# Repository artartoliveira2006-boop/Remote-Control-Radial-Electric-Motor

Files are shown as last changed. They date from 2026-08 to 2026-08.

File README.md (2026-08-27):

# Motor elétrico radial de cinco fases com controle remoto

Protótipo acadêmico de um motor elétrico radial construído com cinco bobinas e controle por uma placa baseada em ESP32. O projeto combina fabricação mecânica, acionamento eletromagnético, sequenciamento de fases e um comando remoto simples consultado pela internet.

<p align="center">
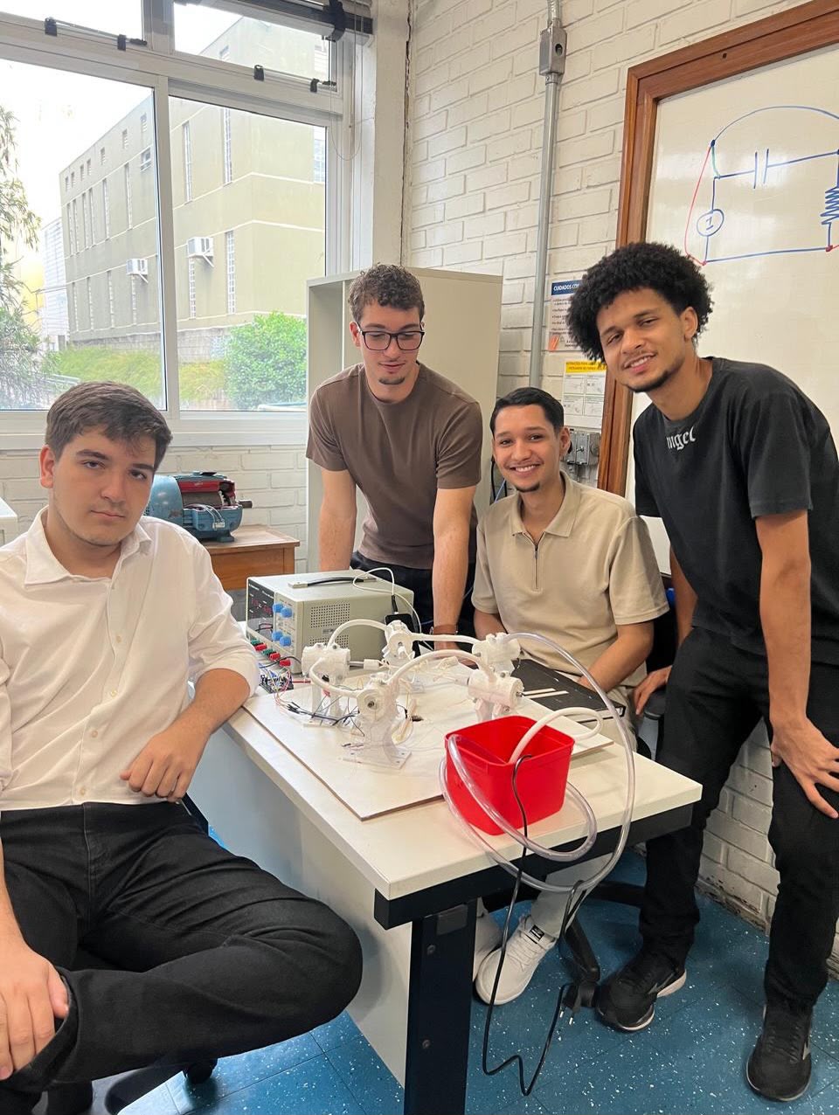
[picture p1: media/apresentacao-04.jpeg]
Equipe ao lado do protótipo de motor radial durante a apresentação
  
</p>

## Visão geral

O rotor é movimentado pela ativação sucessiva das cinco bobinas. O firmware oferece dois mapas de ligação (`MODO 1` e `MODO 2`) e percorre as posições pelo salto matemático `k = 2` em um conjunto de `n = 5`, formando a ordem radial em estrela. O intervalo entre ativações diminui exponencialmente, produzindo uma rampa de aceleração.

Uma tarefa separada do ESP32 consulta, a cada 10 segundos, o arquivo público [`commands.txt`](commands.txt). Os valores aceitos são:

- `MOTOR_ON`: inicia o sequenciamento e zera o cronômetro de aceleração;
- `MOTOR_OFF`: desliga todas as saídas das bobinas.

## Principais recursos

- controle de cinco bobinas por GPIO;
- teste automático individual das bobinas na inicialização;
- dois mapas de pinagem selecionáveis em compilação;
- sequência radial calculada por aritmética modular;
- aceleração com redução exponencial do intervalo entre passos;
- comando remoto por Wi-Fi e arquivo hospedado no GitHub;
- execução da comunicação em uma tarefa separada do sequenciamento.

## Estrutura do repositório

```text
.
|-- cad/
|   |-- bobina.stl
|   |-- encapsulamento-direito.stl
|   |-- encapsulamento-esquerdo.stl
|   `-- README.md
|-- docs/
|   |-- relatorio/
|   |   `-- Motor_Radial_Relatorio_Revisado.tex
|   `-- README.md
|-- firmware/
|   `-- MotorRadial/
|       |-- MotorRadial.ino
|       |-- arduino_secrets.example.h
|       |-- sequenciamento.ino
|       |-- sketch.json
|       |-- variaveis.h
|       `-- wifi.ino
|-- hardware/
|   `-- README.md
|-- media/
|   |-- inspiracao/
|   |   |-- campo-magnetico-solenoide.png
|   |   `-- motor-radial-fiat-a50.jpg
|   |-- apresentacao-01.jpeg
|   |-- apresentacao-02.jpeg
|   |-- apresentacao-03.jpeg
|   |-- apresentacao-04.jpeg
|   |-- demonstracao-01.mp4
|   |-- demonstracao-02.mp4
|   |-- demonstracao-03.mp4
|   |-- demonstracao-04.mp4
|   `-- README.md
|-- output/pdf/
|   `-- Motor_Radial_Relatorio_Revisado.pdf
|-- .gitignore
|-- commands.txt
`-- README.md
```

## Firmware

### Preparar as credenciais

Copie `firmware/MotorRadial/arduino_secrets.example.h` para `firmware/MotorRadial/arduino_secrets.h` e preencha a cópia local:

```cpp
#define SECRET_SSID "NOME_DA_REDE"
#define SECRET_PASSWORD "SENHA_DA_REDE"
```

O arquivo real de credenciais é ignorado pelo Git e não deve ser publicado.

O ZIP público do sketch original continha credenciais diretamente no código. Se aquela senha ainda estiver em uso, altere-a antes de voltar a conectar o protótipo.

### Compilar com Arduino CLI

```bash
arduino-cli core install esp32:esp32
arduino-cli compile --fqbn esp32:esp32:esp32 firmware/MotorRadial
```

A compilação usa `ESP32 Dev Module` como alvo de referência porque o sketch emprega números de GPIO brutos, Wi-Fi e recursos FreeRTOS específicos do ESP32. Confirme o modelo exato da placa física antes de gravar.

Validação realizada com Arduino CLI 1.5.1 e o núcleo oficial Espressif `esp32:esp32` 3.3.11:

- modo 1: 1.022.916 bytes de programa (78%) e 48.504 bytes de memória global (14%);
- modo 2: 1.022.920 bytes de programa (78%) e 48.504 bytes de memória global (14%).

## Sequenciamento

No modo padrão, o atraso entre passos começa em 800 ms e tende a 100 ms, com constante de decaimento de 40 s. O firmware imprime uma RPM estimada com base em uma relação assumida entre passos e revolução; esse valor ainda não foi validado com tacômetro.

Consulte [hardware/README.md](hardware/README.md) antes de energizar o protótipo.

## Atenção antes do primeiro teste

- as bobinas exigem estágio de potência e fonte externa adequada;
- a pinagem física ainda precisa ser confrontada com o protótipo e o Tinkercad;
- o teste de bobinas é executado automaticamente durante a inicialização;
- a função de conexão Wi-Fi aguarda indefinidamente até a rede ficar disponível;
- o comando remoto atual é público e não possui autenticação própria;
- a RPM mostrada no monitor serial é uma estimativa, não uma medição;
- tensão, corrente, aquecimento e velocidade máxima segura ainda precisam ser medidos.

Faça os primeiros testes com alimentação limitada, uma bobina por vez e possibilidade de desligamento imediato.

## Materiais do projeto

- [Sketch no Arduino Cloud](https://app.arduino.cc/sketches/5fc2e5a7-c3c3-415b-b562-e2339e4dc90b?view-mode=preview)
- [Circuito no Tinkercad](https://www.tinkercad.com/things/hriccYSg3r2-dazzling-gaaris-fulffy/editel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)
- [Relatório acadêmico revisado em PDF](output/pdf/Motor_Radial_Relatorio_Revisado.pdf)
- [Fonte LaTeX e instruções de compilação](docs/README.md)
- [Modelos STL para fabricação 3D](cad/README.md)
- [Fotos, vídeos e identificação do material](media/README.md)

## Autoria e contexto acadêmico

O protótipo foi desenvolvido por Arthur Artiaga Oliveira, Matheus Chacon de Moura, Miguel Resende de Faria Silva, Pedro Henrique Rodrigues Meireles e Rafael Valero Borges Alecrim, no curso de Engenharia Elétrica da PUC Minas, como atividade da disciplina Desafio de Engenharia Elétrica I, ministrada pela professora Viviane Reis de Carvalho, em 2026.

## English summary

This repository documents a custom five-phase radial electric motor controlled by an ESP32-class board. Five coils are driven in a star-like modular sequence, with an exponential acceleration ramp and a simple GitHub-hosted remote command. The repository includes sanitized firmware, printable STL meshes, photos, test videos and structured documentation for the circuit and academic report.

## Licença

Uma licença de reutilização ainda não foi definida. Até que os autores escolham uma licença, o conteúdo permanece protegido pelos direitos de seus respectivos autores.

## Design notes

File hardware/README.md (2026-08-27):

# Hardware e montagem

Este diretório registra o circuito de acionamento do motor radial de cinco bobinas. O [projeto compartilhado no Tinkercad](https://www.tinkercad.com/things/hriccYSg3r2-dazzling-gaaris-fulffy/editel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) pode exigir login na Autodesk.

## Sinais usados pelo firmware

No modo sequencial (`MODO == 1`), o firmware usa:

| Saída lógica | GPIO |
| --- | ---: |
| `COIL0_PIN` | 14 |
| `COIL1_PIN` | 17 |
| `COIL2_PIN` | 27 |
| `COIL3_PIN` | 25 |
| `COIL4_PIN` | 16 |

No modo radial (`MODO == 2`), os mesmos GPIOs são associados às saídas em outra ordem. A tabela descreve apenas o firmware; a correspondência física entre saída, transistor e bobina ainda deve ser conferida no protótipo.

## Acionamento e alimentação

As bobinas não podem ser ligadas diretamente aos GPIOs do microcontrolador. O sketch menciona um ULN2003 como estágio de potência. Antes de energizar:

1. confirme a tensão e a corrente nominal de cada bobina;
2. use fonte externa dimensionada para a corrente simultânea prevista;
3. mantenha o GND da fonte, do driver e da placa em comum;
4. confirme a ligação das proteções contra tensão reversa do driver;
5. teste uma bobina por vez, por intervalo curto, observando aquecimento;
6. mantenha um meio físico de cortar a alimentação das bobinas.

O programa executa um teste automático de todas as bobinas na inicialização. Não energize a potência antes de confirmar a pinagem e os limites térmicos.

## Dados ainda necessários

- modelo exato da placa ESP32;
- modelo e quantidade dos drivers;
- tensão, resistência e corrente das bobinas;
- tensão e corrente máxima da fonte;
- diagrama definitivo das ligações;
- identificação física das bobinas 0 a 4.

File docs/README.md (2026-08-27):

# Documentação

O relatório acadêmico foi revisado com base no documento original da equipe e na organização adotada no relatório do projeto da garra articulada.

Arquivos disponíveis:

- [`relatorio/Motor_Radial_Relatorio_Revisado.tex`](relatorio/Motor_Radial_Relatorio_Revisado.tex): fonte editável em LaTeX;
- [`../output/pdf/Motor_Radial_Relatorio_Revisado.pdf`](../output/pdf/Motor_Radial_Relatorio_Revisado.pdf): versão compilada e revisada.

A revisão acrescenta elementos pré-textuais, imagens do projeto, referências visuais licenciadas, tabelas de pinagem e fabricação, metodologia, verificações, segurança e propostas de evolução. Afirmações sobre eficiência, torque, RPM e desempenho térmico foram limitadas ao que pode ser sustentado pelas evidências disponíveis.

Para recompilar a partir da raiz do repositório:

```bash
pdflatex -interaction=nonstopmode -halt-on-error -output-directory=output/pdf docs/relatorio/Motor_Radial_Relatorio_Revisado.tex
pdflatex -interaction=nonstopmode -halt-on-error -output-directory=output/pdf docs/relatorio/Motor_Radial_Relatorio_Revisado.tex
```

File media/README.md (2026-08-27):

# Fotos e vídeos

Este diretório preserva quatro registros fotográficos do dia da apresentação e quatro vídeos recebidos junto aos materiais do projeto.

## Fotos

- `apresentacao-01.jpeg`: demonstração do protótipo em bancada;
- `apresentacao-02.jpeg`: equipe e docente junto ao protótipo;
- `apresentacao-03.jpeg`: explicação durante a apresentação;
- `apresentacao-04.jpeg`: equipe junto ao protótipo.

## Vídeos

| Arquivo | Duração | Orientação |
| --- | ---: | --- |
| `demonstracao-01.mp4` | 39 s | horizontal |
| `demonstracao-02.mp4` | 8 s | vertical |
| `demonstracao-03.mp4` | 17 s | horizontal |
| `demonstracao-04.mp4` | 4 min | horizontal |

Os vídeos foram mantidos com nomes neutros porque o conteúdo individual ainda não foi reproduzido nesta revisão. Após confirmação, eles podem receber nomes específicos como `motor-em-funcionamento.mp4` e `teste-bobina-01.mp4`.

As imagens mostram integrantes, docentes e/ou visitantes. A equipe deve manter no repositório apenas os registros cuja publicação tenha sido autorizada.

## Imagens de inspiração

- `inspiracao/motor-radial-fiat-a50.jpg`: motor radial aeronáutico Fiat A.50 seccionado, fotografia de MLWatts, Wikimedia Commons, licença CC BY-SA 3.0;
- `inspiracao/campo-magnetico-solenoide.png`: representação das linhas de campo de um solenoide, por Nuno Nogueira, Wikimedia Commons, domínio público.

Essas imagens são usadas no relatório como referências visuais e conceituais. Elas não representam componentes idênticos aos empregados no protótipo.

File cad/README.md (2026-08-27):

# Modelos para fabricação 3D

Esta pasta contém três malhas STL binárias fornecidas a partir do projeto mecânico:

| Arquivo | Função informada | Triângulos | Dimensões da malha (X x Y x Z) |
| --- | --- | ---: | --- |
| `bobina.stl` | Corpo/suporte da bobina | 1.804 | 40,00 x 39,98 x 80,00 |
| `encapsulamento-esquerdo.stl` | Metade esquerda do encapsulamento | 766 | 29,00 x 64,27 x 80,00 |
| `encapsulamento-direito.stl` | Metade direita do encapsulamento | 766 | 24,00 x 64,27 x 80,00 |

As dimensões acima foram calculadas a partir dos limites geométricos dos arquivos. O formato STL não armazena a unidade de medida; confirme no software de modelagem ou fatiamento se os valores devem ser interpretados em milímetros antes de fabricar.

## Arquivos que ainda podem complementar o projeto

- modelo paramétrico original ou conjunto em `.step`/`.stp`;
- imagem renderizada ou captura da montagem completa;
- nome e versão do software usado na modelagem;
- orientação, preenchimento, material e demais parâmetros de impressão;
- tolerâncias e método de união das duas metades do encapsulamento.

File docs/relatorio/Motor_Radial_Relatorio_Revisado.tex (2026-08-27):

\documentclass[12pt,a4paper,oneside]{article}

\usepackage[T1]{fontenc}
\usepackage[utf8]{inputenc}
\usepackage{lmodern}
\usepackage[english,brazilian]{babel}
\usepackage{geometry}
\usepackage{graphicx}
\usepackage{booktabs}
\usepackage{tabularx}
\usepackage{array}
\usepackage{longtable}
\usepackage{enumitem}
\usepackage{caption}
\usepackage{float}
\usepackage{xcolor}
\usepackage{fancyhdr}
\usepackage{titlesec}
\usepackage{microtype}
\usepackage{setspace}
\usepackage{hyperref}
\usepackage{url}

\geometry{top=2.5cm,bottom=2.2cm,left=3cm,right=2cm,headheight=24pt}
\setlength{\parindent}{1.25cm}
\setlength{\parskip}{0pt}
\onehalfspacing
\emergencystretch=2em

\definecolor{navy}{HTML}{15324A}
\definecolor{blue}{HTML}{247BA0}
\definecolor{cyan}{HTML}{5BC0BE}
\definecolor{pale}{HTML}{EAF4F7}
\definecolor{orange}{HTML}{F28F3B}
\definecolor{dark}{HTML}{202A33}

\hypersetup{
  colorlinks=true,
  linkcolor=navy,
  urlcolor=blue,
  citecolor=navy,
  pdftitle={Motor radial elétrico experimental de cinco atuadores},
  pdfauthor={Arthur Artiaga Oliveira; Matheus Chacon de Moura; Miguel Resende de Faria Silva; Pedro Henrique Rodrigues Meireles; Rafael Valero Borges Alecrim}
}

\titleformat{\section}{\normalfont\Large\bfseries\color{navy}}{\thesection}{0.6em}{}
\titleformat{\subsection}{\normalfont\large\bfseries\color{blue}}{\thesubsection}{0.6em}{}
\titleformat{\subsubsection}{\normalfont\normalsize\bfseries\color{dark}}{\thesubsubsection}{0.6em}{}
\titlespacing*{\section}{0pt}{1.5em}{0.7em}
\titlespacing*{\subsection}{0pt}{1.1em}{0.5em}

\pagestyle{fancy}
\fancyhf{}
\fancyhead[L]{\footnotesize\color{navy} MOTOR RADIAL ELÉTRICO EXPERIMENTAL}
\fancyhead[R]{\footnotesize\color{gray} PUC MINAS}
\fancyfoot[C]{\thepage}
\renewcommand{\headrulewidth}{0.4pt}
\renewcommand{\headrule}{\hbox to\headwidth{\color{cyan}\leaders\hrule height \headrulewidth\hfill}}

\captionsetup{font=small,labelfont=bf,textfont=it,justification=centering}
\setlist[itemize]{leftmargin=1.2cm,itemsep=0.2em,topsep=0.4em}
\newcolumntype{Y}{>{\raggedright\arraybackslash}X}
\renewcommand{\refname}{REFERÊNCIAS}
\newcommand{\source}[1]{\par\centering\footnotesize\itshape Fonte: #1\par}
\newcommand{\warningbox}[1]{%
  \begin{center}
  \colorbox{pale}{\parbox{0.92\textwidth}{\color{navy}\small #1}}
  \end{center}
}

\begin{document}
\hypersetup{pageanchor=false}

% Capa
\begin{titlepage}
  \pagecolor{navy}\color{white}
  \noindent {\large INSTITUTO POLITÉCNICO - PUC MINAS}\\[0.25cm]
  {\large CURSO DE ENGENHARIA ELÉTRICA}

  \vspace{3.2cm}
  {\fontsize{25}{31}\selectfont\bfseries
  DESENVOLVIMENTO DE UM MOTOR RADIAL ELÉTRICO EXPERIMENTAL DE CINCO ATUADORES\par}

  \vspace{0.8cm}
  {\color{orange}\rule{0.48\textwidth}{2.2pt}}\\[0.8cm]
  {\large Controle embarcado, fabricação aditiva e investigação de resfriamento líquido}

  \vfill
  {\normalsize
  Arthur Artiaga Oliveira\\
  Matheus Chacon de Moura\\
  Miguel Resende de Faria Silva\\
  Pedro Henrique Rodrigues Meireles\\
  Rafael Valero Borges Alecrim}

  \vspace{1.2cm}
  {\normalsize Belo Horizonte - MG\\2026}
\end{titlepage}
\nopagecolor\color{dark}

% Folha de rosto, seguindo a estrutura do relatório de referência
\begin{titlepage}
  \begin{center}
    {\normalsize
    Arthur Artiaga Oliveira\\
    Matheus Chacon de Moura\\
    Miguel Resende de Faria Silva\\
    Pedro Henrique Rodrigues Meireles\\
    Rafael Valero Borges Alecrim}

    \vspace{3.2cm}
    {\Large\bfseries DESENVOLVIMENTO DE UM MOTOR RADIAL ELÉTRICO EXPERIMENTAL DE CINCO ATUADORES\par}
  \end{center}

  \vspace{3.2cm}
  \hfill\begin{minipage}{0.52\textwidth}
    Trabalho apresentado ao Curso de Engenharia Elétrica da Pontifícia Universidade Católica de Minas Gerais, no âmbito da disciplina Desafio de Engenharia Elétrica I.

    \vspace{0.5cm}
    Professora: Viviane Reis de Carvalho.
  \end{minipage}

  \vfill
  \begin{center}
    Belo Horizonte - MG\\
    2026
  \end{center}
\end{titlepage}

\hypersetup{pageanchor=true}
\pagenumbering{roman}

\section*{RESUMO}
\addcontentsline{toc}{section}{Resumo}
Este relatório descreve o desenvolvimento de um protótipo didático de motor radial elétrico com cinco atuadores eletromagnéticos dispostos em estrela. A estrutura combina peças impressas em 3D, base de madeira e componentes metálicos reaproveitados. Um microcontrolador ESP32 executa o acionamento sequencial das bobinas por intermédio de um estágio ULN2003 e consulta, via Wi-Fi, um comando textual hospedado no GitHub. O firmware implementa duas ordens de comutação, teste individual dos atuadores e redução progressiva do intervalo entre passos. As demonstrações registradas confirmam qualitativamente a energização das bobinas e o movimento do conjunto; entretanto, não foram disponibilizadas medições instrumentais de rotação, torque, corrente ou temperatura. Por esse motivo, o desempenho e a efetividade do resfriamento líquido são tratados como aspectos ainda sujeitos a validação experimental. O trabalho evidencia a integração entre eletromagnetismo, sistemas embarcados, fabricação aditiva e reaproveitamento de materiais, além de estabelecer uma base documentada para ensaios futuros.

\noindent\textbf{Palavras-chave:} motor radial; eletromagnetismo; ESP32; ULN2003; fabricação aditiva; protótipo didático.
\clearpage

\selectlanguage{english}
\section*{ABSTRACT}
\addcontentsline{toc}{section}{Abstract}
This report describes the development of a didactic radial electric motor prototype with five electromagnetic actuators arranged in a star pattern. Its structure combines 3D-printed parts, a wooden base and reused metallic components. An ESP32 microcontroller sequentially drives the coils through a ULN2003 stage and checks a text command hosted on GitHub over Wi-Fi. The firmware provides two switching orders, individual actuator testing and a progressive reduction of the interval between steps. Available demonstrations qualitatively confirm coil energization and motion of the assembly; however, no instrumented measurements of speed, torque, current or temperature were available. Performance and liquid-cooling effectiveness are therefore identified as subjects for future experimental validation. The project integrates electromagnetism, embedded systems, additive manufacturing and material reuse while establishing a documented baseline for further testing.

\noindent\textbf{Keywords:} radial motor; electromagnetism; ESP32; ULN2003; additive manufacturing; educational prototype.
\selectlanguage{brazilian}
\clearpage

\listoffigures
\addcontentsline{toc}{section}{Lista de figuras}
\clearpage

\section*{LISTA DE SIGLAS E ABREVIATURAS}
\addcontentsline{toc}{section}{Lista de siglas e abreviaturas}
\begin{tabularx}{\textwidth}{>{\bfseries}l Y}
CAD & Computer-Aided Design (projeto auxiliado por computador)\\
ESP32 & Família de microcontroladores com conectividade sem fio da Espressif\\
FreeRTOS & Sistema operacional de tempo real usado pelo firmware\\
GPIO & General-Purpose Input/Output (entrada e saída de uso geral)\\
HTTP & Hypertext Transfer Protocol\\
IoT & Internet of Things (Internet das Coisas)\\
RPM & Rotações por minuto\\
STL & Formato de malha empregado na fabricação aditiva\\
Wi-Fi & Tecnologia de comunicação em rede sem fio\\
\end{tabularx}
\clearpage

\tableofcontents
\clearpage
\pagenumbering{arabic}

\section{INTRODUÇÃO}

Motores elétricos convertem energia elétrica em energia mecânica por meio da interação entre campos magnéticos. No protótipo estudado, essa conversão é explorada em uma arquitetura inspirada visualmente nos motores radiais: cinco eletroímãs são distribuídos ao redor de um conjunto móvel central e acionados em sequência.

A proposta foi desenvolvida no primeiro semestre do curso de Engenharia Elétrica como exercício interdisciplinar. Além da montagem eletromecânica, o trabalho reuniu modelagem CAD, impressão 3D, programação embarcada, comunicação em rede e reaproveitamento de materiais. O resultado deve ser compreendido como protótipo experimental e didático, não como máquina elétrica caracterizada para operação contínua.

\warningbox{Esta versão revisada separa fatos documentados de hipóteses e observações. Afirmações quantitativas sobre eficiência, torque, velocidade ou desempenho térmico somente poderão ser feitas após ensaios instrumentados.}

\subsection{Problemática e justificativa}

O desafio consistiu em produzir movimento rotativo a partir do acionamento coordenado de cinco bobinas, usando uma estrutura de baixo custo e um controlador programável. O aquecimento por efeito Joule motivou também a incorporação de passagens para circulação de água nos encapsulamentos das bobinas, conceito que requer validação térmica posterior.

A documentação técnica é parte do problema de engenharia. Sem o registro de pinagem, lógica de controle, modelos de fabricação e limitações dos ensaios, torna-se difícil reproduzir o protótipo ou comparar futuras alterações. Assim, este relatório reúne o estado conhecido do sistema e explicita os dados que ainda precisam ser medidos.

\subsection{Referências visuais e conceituais}

A organização em estrela foi inspirada na leitura visual dos motores radiais aeronáuticos, nos quais os cilindros se distribuem ao redor de um eixo central. A semelhança é geométrica: o protótipo elétrico não reproduz combustão interna, bielas articuladas ou o ciclo termodinâmico dessas máquinas.

\begin{figure}[H]
  \centering
  
  \caption{Motor aeronáutico radial Fiat A.50 seccionado, referência para a disposição em estrela.}
  \source{MLWatts, Wikimedia Commons, 2012, licença CC BY-SA 3.0.}
\end{figure}

O princípio de atuação, por sua vez, vem do campo magnético produzido por uma bobina energizada. A Figura~\ref{fig:solenoide} é conceitual e não representa a geometria exata dos atuadores construídos.

\begin{figure}[H]
  \centering
  
  \caption{Representação aproximada das linhas de campo de um solenoide.}
  \label{fig:solenoide}
  \source{Nuno Nogueira, Wikimedia Commons, domínio público.}
\end{figure}

\subsection{Objetivos}

\subsubsection{Objetivo geral}

Projetar, construir e demonstrar um protótipo de motor radial elétrico com cinco atuadores, controle embarcado e componentes produzidos por fabricação aditiva.

\subsubsection{Objetivos específicos}

\begin{itemize}
  \item modelar e fabricar suportes e encapsulamentos por impressão 3D;
  \item construir e testar cinco bobinas eletromagnéticas;
  \item implementar o acionamento sequencial por ESP32 e ULN2003;
  \item permitir habilitação remota por consulta a um comando hospedado no GitHub;
  \item investigar uma solução de circulação de água para remoção de calor;
  \item documentar limitações e definir ensaios para a continuidade do projeto.
\end{itemize}

\section{REFERENCIAL TEÓRICO}

\subsection{Eletromagnetismo e atuação}

A corrente elétrica que percorre uma bobina produz um campo magnético. Quando o atuador é energizado, esse campo exerce força sobre o elemento ferromagnético associado ao mecanismo móvel. A repetição ordenada das atrações produz deslocamentos angulares sucessivos. A intensidade da força depende, entre outros fatores, da corrente, do número de espiras, da geometria do núcleo e do entreferro \cite{halliday,fitzgerald}.

\subsection{Aquecimento por efeito Joule}

A dissipação elétrica em uma bobina pode ser estimada por
\begin{equation}
  P = R I^2,
\end{equation}
em que $P$ é a potência dissipada, $R$ é a resistência do enrolamento e $I$ é a corrente. Como o aquecimento varia com o quadrado da corrente, a caracterização elétrica e térmica é essencial antes de aumentar o tempo de energização ou a tensão de alimentação.

\subsection{Controle embarcado e estágio de potência}

Os pinos do ESP32 fornecem sinais lógicos e não devem alimentar bobinas diretamente. O ULN2003 reúne transistores Darlington usados como chaves de baixa tensão, permitindo que os sinais do microcontrolador comandem cargas ligadas a uma fonte externa \cite{tiuln}. O retorno de corrente, a conexão comum dos diodos internos, o aterramento compartilhado e os limites elétricos do componente precisam ser respeitados na montagem.

\begin{figure}[H]
  \centering
  \setlength{\fboxsep}{8pt}
  \fbox{Comando remoto GitHub}
  $\longrightarrow$
  \fbox{ESP32 + Wi-Fi}
  $\longrightarrow$
  \fbox{ULN2003}
  $\longrightarrow$
  \fbox{5 bobinas}
  \caption{Arquitetura funcional documentada do protótipo.}
  \source{Elaboração própria.}
\end{figure}

\subsection{Configuração radial}

Nos motores aeronáuticos radiais, cilindros são distribuídos ao redor de um eixo comum. Neste trabalho, a configuração foi reinterpretada como disposição de cinco atuadores eletromagnéticos em estrela. A comparação orienta a forma do conjunto, mas não implica equivalência entre os princípios de conversão de energia.

\section{METODOLOGIA E DESENVOLVIMENTO}

\subsection{Fluxo de atividades}

O desenvolvimento foi conduzido em etapas interdependentes:
\begin{enumerate}[leftmargin=1.4cm]
  \item definição da configuração radial e modelagem das peças;
  \item impressão dos suportes e encapsulamentos;
  \item construção dos enrolamentos e montagem dos elementos ferromagnéticos;
  \item integração mecânica sobre a base de madeira;
  \item montagem do ESP32 e do estágio ULN2003;
  \item desenvolvimento e compilação do firmware;
  \item teste individual das cinco saídas;
  \item execução da sequência e registro da demonstração.
\end{enumerate}

\subsection{Componentes utilizados}

\begin{table}[H]
\centering
\caption{Componentes identificados na documentação disponível.}
\begin{tabularx}{\textwidth}{>{\bfseries}p{4.2cm}Y}
\toprule
Componente & Função no protótipo\\
\midrule
ESP32 & Sequenciamento das bobinas e consulta ao comando remoto por Wi-Fi.\\
ULN2003 & Chaveamento das cargas a partir dos sinais lógicos do ESP32.\\
Cinco bobinas & Produção dos campos magnéticos de atuação.\\
Fonte externa & Alimentação do estágio de potência e dos enrolamentos.\\
Peças impressas em 3D & Suporte das bobinas e encapsulamento com passagens para água.\\
Base de madeira & Sustentação do conjunto eletromecânico.\\
Componentes metálicos & Elementos móveis, eixo e partes ferromagnéticas.\\
Tubulações e reservatório & Circulação experimental de água nos encapsulamentos.\\
\bottomrule
\end{tabularx}
\end{table}

\subsection{Estrutura mecânica e fabricação aditiva}

A montagem adota cinco posições radiais em torno do rotor. A base foi construída em madeira e recebeu componentes metálicos reutilizados. Foram disponibilizadas três malhas STL: suporte da bobina e metades esquerda e direita do encapsulamento. Como o formato STL não registra unidade, as dimensões devem ser confirmadas no software CAD ou fatiador antes da fabricação.

\begin{table}[H]
\centering
\caption{Características extraídas das malhas STL.}
\begin{tabularx}{\textwidth}{Y c c}
\toprule
Modelo & Triângulos & Dimensões geométricas X $\times$ Y $\times$ Z\\
\midrule
Bobina & 1.804 & 40,00 $\times$ 39,98 $\times$ 80,00\\
Encapsulamento esquerdo & 766 & 29,00 $\times$ 64,27 $\times$ 80,00\\
Encapsulamento direito & 766 & 24,00 $\times$ 64,27 $\times$ 80,00\\
\bottomrule
\end{tabularx}
\end{table}

As dimensões da Tabela 2 são limites geométricos da malha. As unidades não são codificadas no arquivo e precisam ser confirmadas antes da impressão.

\subsection{Subsistema eletromagnético e resfriamento}

Cada atuador é formado por um enrolamento de fio de cobre esmaltado e um elemento ferromagnético móvel. Os encapsulamentos foram concebidos com passagens para água. A existência desse circuito de circulação é documentada, mas sua contribuição térmica ainda não foi quantificada por comparação de temperaturas, vazões ou tempos de operação.

\begin{figure}[H]
  \centering
  \begin{tabular}{cc}
     &
     \\
     &
    
  \end{tabular}
  \caption{Registros do protótipo e da apresentação acadêmica.}
  \source{Acervo da equipe.}
\end{figure}

\subsection{Eletrônica e pinagem}

\begin{table}[H]
\centering
\caption{Mapeamentos definidos no firmware.}
\small
\begin{tabularx}{\textwidth}{p{2.5cm} >{\centering\arraybackslash}p{2.7cm} >{\centering\arraybackslash}p{2.7cm} Y}
\toprule
Canal lógico & GPIO no modo 1 & GPIO no modo 2 & Função\\
\midrule
Bobina 0 & 14 & 17 & Primeiro atuador da sequência\\
Bobina 1 & 17 & 25 & Segundo atuador da sequência\\
Bobina 2 & 27 & 14 & Terceiro atuador da sequência\\
Bobina 3 & 25 & 16 & Quarto atuador da sequência\\
Bobina 4 & 16 & 27 & Quinto atuador da sequência\\
\bottomrule
\end{tabularx}
\end{table}

\warningbox{O circuito completo do Tinkercad depende de autenticação para inspeção. A documentação disponível ainda não confirma tensão da fonte, resistência das bobinas, corrente por canal, ligação do terminal COM ou capacidade térmica do driver.}

\subsection{Programação do sistema de controle}

\subsubsection{Organização geral}

O firmware foi organizado em módulos para variáveis, sequenciamento e comunicação Wi-Fi. As credenciais de rede foram removidas do código versionado e substituídas por um arquivo local ignorado pelo Git. Uma tarefa FreeRTOS fixada ao segundo núcleo consulta periodicamente o comando remoto, enquanto o laço principal executa a sequência eletromagnética.

\subsubsection{Teste de inicialização}

Antes da rotina principal, as cinco saídas são acionadas individualmente. Essa etapa permite verificar a resposta de cada canal, mas deve ser executada com alimentação limitada e possibilidade de desligamento imediato.

\subsubsection{Sequência e aceleração}

A posição lógica seguinte é obtida por aritmética modular, fazendo a sequência retornar ao início após a quinta bobina. O intervalo entre passos parte de aproximadamente 800 ms e decresce exponencialmente em direção a 100 ms, com constante temporal configurada em 40 s. O número apresentado como RPM no monitor serial é uma estimativa baseada em uma relação assumida entre passos e revolução; não substitui medição por tacômetro.

\begin{table}[H]
\centering
\caption{Modos de sequência do firmware revisado.}
\begin{tabularx}{0.78\textwidth}{c Y c}
\toprule
Modo & Ordem dos GPIOs & Compilação\\
\midrule
1 & 14, 17, 27, 25, 16 & Aprovada\\
2 & 17, 25, 14, 16, 27 & Aprovada\\
\bottomrule
\end{tabularx}
\end{table}

\subsubsection{Comando remoto}

O ESP32 realiza uma requisição HTTP ao arquivo \texttt{commands.txt} hospedado no GitHub. Quando recebe o texto \texttt{MOTOR\_ON}, habilita o funcionamento; qualquer outro conteúdo desabilita o acionamento. Essa solução é adequada à demonstração, mas não oferece autenticação própria, resposta em tempo real garantida ou proteção contra indisponibilidade da rede.

\section{TESTES E VERIFICAÇÕES}

\subsection{Verificação de software}

A versão sanitizada foi compilada com Arduino CLI 1.5.1 para o alvo ESP32 Dev Module, usando o núcleo oficial Espressif \texttt{esp32:esp32} 3.3.11. Os dois modos de pinagem compilaram sem erro.

\begin{table}[H]
\centering
\caption{Resultado da compilação do firmware.}
\begin{tabularx}{0.88\textwidth}{p{3cm} Y Y}
\toprule
Configuração & Programa & Memória global\\
\midrule
Modo 1 & 1.022.916 bytes (78\%) & 48.504 bytes (14\%)\\
Modo 2 & 1.022.920 bytes (78\%) & 48.504 bytes (14\%)\\
\bottomrule
\end{tabularx}
\end{table}

Esse ensaio verifica a consistência do software e das dependências de compilação. Ele não comprova o comportamento elétrico do protótipo.

\subsection{Testes documentados}

Os materiais fornecidos incluem registros da apresentação, vídeos do motor e testes das bobinas. Esses registros permitem documentar a construção e a ocorrência de resposta eletromecânica. Não foram disponibilizados arquivos de aquisição de dados ou instrumentos de medição associados aos testes.

\subsection{Procedimento recomendado para ensaios futuros}

\begin{enumerate}[leftmargin=1.4cm]
  \item medir resistência e continuidade de cada bobina com o sistema desligado;
  \item energizar um canal por vez com fonte limitada em corrente;
  \item registrar tensão, corrente e temperatura em intervalos definidos;
  \item verificar a ordem física das bobinas em baixa velocidade;
  \item medir RPM com sensor óptico ou Hall;
  \item repetir o ensaio térmico com circulação desligada e ligada;
  \item registrar vazão, temperatura ambiente e tempo de operação;
  \item interromper imediatamente o teste diante de aquecimento, vazamento ou travamento.
\end{enumerate}

\section{RESULTADOS E DISCUSSÃO}

\subsection{Evidências disponíveis}

As fotografias e os vídeos disponibilizados registram o protótipo, a apresentação e demonstrações associadas ao motor e às bobinas. O material sustenta a conclusão qualitativa de que o conjunto foi construído e apresentado e de que houve resposta eletromecânica durante os testes. O firmware disponível também documenta o acionamento das cinco saídas e a lógica de habilitação remota.

\subsection{Limites das conclusões}

\begin{longtable}{p{2.6cm}p{5.0cm}p{7.0cm}}
\caption{Separação entre evidência disponível e caracterização pendente.}\\
\toprule
\textbf{Aspecto} & \textbf{O que está documentado} & \textbf{O que ainda deve ser medido}\\
\midrule
\endfirsthead
\toprule
\textbf{Aspecto} & \textbf{O que está documentado} & \textbf{O que ainda deve ser medido}\\
\midrule
\endhead
Movimento & Observação audiovisual & RPM real, estabilidade e faixa operacional\\
Atuação & Teste sequencial de cinco saídas & Corrente, força e repetibilidade por bobina\\
Térmica & Encapsulamento com circulação de água & Temperatura, vazão e comparação com e sem fluxo\\
Desempenho & Protótipo funcional em demonstração & Torque, potência mecânica, rendimento e autonomia\\
Controle remoto & Consulta HTTP ao GitHub & Latência, falhas de rede e segurança\\
\bottomrule
\end{longtable}

\warningbox{Sem dados instrumentais, não é possível afirmar ganho de eficiência, redução mensurável de temperatura ou controle preciso de velocidade. Essas afirmações foram retiradas da conclusão para preservar a validade acadêmica do relatório.}

\subsection{Relevância acadêmica}

O protótipo integra conceitos de eletromagnetismo, eletrônica de potência, sistemas embarcados, programação concorrente, fabricação aditiva e segurança experimental. As limitações encontradas não anulam seu valor didático; ao contrário, definem problemas concretos de dimensionamento e instrumentação para uma próxima etapa.

\section{SUSTENTABILIDADE E SEGURANÇA}

\subsection{Reaproveitamento de materiais}

A base de madeira e os componentes metálicos reaproveitados reduziram a necessidade de aquisição de material novo. A fabricação aditiva também permitiu produzir geometrias específicas para o protótipo. Uma avaliação ambiental completa, contudo, exigiria contabilizar massa de material, consumo de impressão, descarte e possibilidade de reutilização.

\subsection{Cuidados para novos ensaios}

\begin{itemize}
  \item usar fonte com limitação de corrente e proteção adequada;
  \item confirmar a corrente máxima das bobinas e a dissipação admissível do ULN2003;
  \item garantir aterramento comum e diodos de roda livre corretamente conectados;
  \item manter água e conexões hidráulicas isoladas da eletrônica;
  \item monitorar a temperatura dos enrolamentos e do driver;
  \item prever desligamento imediato e impedir contato com partes móveis;
  \item não operar o motor sem supervisão enquanto os limites não forem caracterizados.
\end{itemize}

\section{PROPOSTAS DE OTIMIZAÇÃO E EVOLUÇÃO}

\begin{itemize}
  \item medir resistência e indutância de cada bobina;
  \item registrar tensão e corrente por canal com e sem carga;
  \item medir RPM por sensor óptico ou Hall e torque por bancada apropriada;
  \item comparar curvas de temperatura com circulação desligada e ligada;
  \item documentar vazão, fluido, vedação e pressão do circuito de resfriamento;
  \item substituir a consulta pública por uma interface autenticada e tolerante a falhas;
  \item validar esquemático, dimensionamento do driver e modelo exato da placa ESP32;
  \item preservar o arquivo CAD paramétrico e registrar parâmetros de impressão.
\end{itemize}

\section{CONCLUSÃO}

O projeto atingiu seu propósito didático ao integrar uma montagem mecânica radial, cinco atuadores eletromagnéticos, fabricação aditiva, controle por ESP32 e comunicação em rede. O protótipo e seus registros demonstram a realização prática da proposta e oferecem uma plataforma concreta para estudo de comutação, eletromagnetismo e sistemas embarcados.

A principal contribuição desta revisão é tornar explícita a diferença entre funcionamento observado e desempenho medido. A compilação do firmware foi verificada, mas as grandezas elétricas, mecânicas e térmicas permanecem sem caracterização quantitativa. A continuidade do trabalho deve priorizar esses ensaios e a segurança do estágio de potência.

Com a documentação do código, das malhas STL e das limitações atuais, o projeto passa a contar com uma base mais reproduzível e tecnicamente defensável para aperfeiçoamentos futuros.

\clearpage
\phantomsection\addcontentsline{toc}{section}{Referências}
\begin{thebibliography}{99}
\bibitem{chapman} CHAPMAN, Stephen J. \textit{Fundamentos de máquinas elétricas}. 5. ed. Porto Alegre: AMGH, 2013.

\bibitem{espressif} ESPRESSIF SYSTEMS. \textit{ESP32 Series Datasheet}. Documentação técnica do fabricante. Disponível em: \url{https://www.espressif.com/en/support/documents/technical-documents}. Acesso em: 27 ago. 2026.

\bibitem{fitzgerald} FITZGERALD, A. E.; KINGSLEY JR., C.; UMANS, S. D. \textit{Máquinas elétricas}. 7. ed. Porto Alegre: Bookman, 2014.

\bibitem{halliday} HALLIDAY, D.; RESNICK, R.; WALKER, J. \textit{Fundamentos de física}. v. 3. Rio de Janeiro: LTC, 2016.

\bibitem{fiat} MLWATTS. \textit{Fiat A.50 radial engine front view}. Wikimedia Commons, 2012. Licença CC BY-SA 3.0. Disponível em: \url{https://commons.wikimedia.org/wiki/File:Fiat_A.50_radial_engine_front_view.JPG}. Acesso em: 27 ago. 2026.

\bibitem{solenoide} NOGUEIRA, Nuno. \textit{Solenoid Rotated}. Wikimedia Commons, 2009. Domínio público. Disponível em: \url{https://commons.wikimedia.org/wiki/File:Solenoid_Rotated.svg}. Acesso em: 27 ago. 2026.

\bibitem{sedra} SEDRA, A. S.; SMITH, K. C. \textit{Microeletrônica}. 7. ed. São Paulo: Pearson, 2015.

\bibitem{tiuln} TEXAS INSTRUMENTS. \textit{ULN200x, ULQ200x High-Voltage, High-Current Darlington Transistor Arrays}. Datasheet. Disponível em: \url{https://www.ti.com/lit/ds/symlink/uln2003a.pdf}. Acesso em: 27 ago. 2026.
\end{thebibliography}

\clearpage
\section*{APÊNDICE A - REPOSITÓRIO E MATERIAIS}
\addcontentsline{toc}{section}{Apêndice A - Repositório e materiais}

\noindent\textbf{Repositório do projeto:}\\
\href{https://github.com/artartoliveira2006-boop/Remote-Control-Radial-Electric-Motor}{GitHub - Remote-Control-Radial-Electric-Motor}

\noindent\textbf{Sketch de origem:}\\
\href{https://app.arduino.cc/sketches/5fc2e5a7-c3c3-415b-b562-e2339e4dc90b?view-mode=preview}{Arduino Cloud - MotorRadial}

\noindent\textbf{Circuito compartilhado:}\\
\href{https://www.tinkercad.com/things/hriccYSg3r2-dazzling-gaaris-fulffy}{Tinkercad - circuito compartilhado}

O repositório preserva o firmware sanitizado, arquivos STL, fotografias, vídeos e documentação complementar. Credenciais de rede não fazem parte dos arquivos versionados.

\end{document}

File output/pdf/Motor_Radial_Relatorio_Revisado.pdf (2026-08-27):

### INSTITUTO POLITÉCNICO - PUC MINAS

### CURSO DE ENGENHARIA ELÉTRICA

# DESENVOLVIMENTO DE UM MOTOR RADIAL ELÉTRICO EX-

# PERIMENTAL DE CINCO ATUA-

# DORES

### Controle embarcado, fabricação aditiva e investigação de resfriamento líquido

Arthur Artiaga Oliveira
Matheus Chacon de Moura
Miguel Resende de Faria Silva Pedro Henrique Rodrigues Meireles Rafael Valero Borges Alecrim

Belo Horizonte - MG

Arthur Artiaga Oliveira
Matheus Chacon de Moura
Miguel Resende de Faria Silva Pedro Henrique Rodrigues Meireles Rafael Valero Borges Alecrim

## DESENVOLVIMENTO DE UM MOTOR RADIAL ELÉTRICO EXPERIMENTAL DE CINCO

## ATUADORES

Trabalho apresentado ao Curso de Engenharia Elétrica da Pontifícia Universidade Católica de Minas Gerais, no âmbito da disciplina Desafio de Engenharia Elétrica I.

Professora: Viviane Reis de Carvalho.

Belo Horizonte - MG
2026

MOTOR RADIAL ELÉTRICO EXPERIMENTAL | PUC MINAS

## RESUMO

Este relatório descreve o desenvolvimento de um protótipo didático de motor radial elétrico com cinco atuadores eletromagnéticos dispostos em estrela. A estrutura combina peças impressas em 3D, base de madeira e componentes metálicos reaproveitados. Um microcontrolador ESP32 executa o acionamento sequencial das bobinas por intermédio de um estágio ULN2003 e consulta, via Wi-Fi, um comando textual hospedado no GitHub. O firmware implementa duas ordens de comutação, teste individual dos atuadores e redução progressiva do intervalo entre passos. As demonstrações registradas confirmam qualitativamente a energização das bobinas e o movimento do conjunto; entretanto, não foram disponibilizadas medições instrumentais de rotação, torque, corrente ou temperatura. Por esse motivo, o desempenho e a efetividade do resfriamento líquido são tratados como aspectos ainda sujeitos a validação experimental. O trabalho evidencia a integração entre eletromagnetismo, sistemas embarcados, fabricação aditiva e reaproveitamento de materiais, além de estabelecer uma base documentada para ensaios futuros. Palavras-chave: motor radial; eletromagnetismo; ESP32; ULN2003; fabricação aditiva; protótipo didático.

i

## ABSTRACT

This report describes the development of a didactic radial electric motor prototype with five electromagnetic actuators arranged in a star pattern. Its structure combines 3Dprinted parts, a wooden base and reused metallic components. An ESP32 microcontroller sequentially drives the coils through a ULN2003 stage and checks a text command hosted on GitHub over Wi-Fi. The firmware provides two switching orders, individual actuator testing and a progressive reduction of the interval between steps. Available demonstrations qualitatively confirm coil energization and motion of the assembly; however, no instrumented measurements of speed, torque, current or temperature were available. Performance and liquid-cooling effectiveness are therefore identified as subjects for future experimental validation. The project integrates electromagnetism, embedded systems, additive manufacturing and material reuse while establishing a documented baseline for further testing.
Keywords: radial motor; electromagnetism; ESP32; ULN2003; additive manufacturing; educational prototype.

ii

## Lista de Figuras

1 | Motor aeronáutico radial Fiat A.50 seccionado, referência para a disposição
| em estrela | | 2
2 | Representação aproximada das linhas de campo de um solenoide | | 2
3 | Arquitetura funcional documentada do protótipo | | 3
4 | Registros do protótipo e da apresentação acadêmica | | 5

iii

## LISTA DE SIGLAS E ABREVIATURAS

CAD | Computer-Aided Design (projeto auxiliado por computador)
ESP32 | Família de microcontroladores com conectividade sem fio da Espressif
FreeRTOS Sistema operacional de tempo real usado pelo firmware
GPIO | General-Purpose Input/Output (entrada e saída de uso geral)
HTTP | Hypertext Transfer Protocol
IoT | Internet of Things (Internet das Coisas)
RPM | Rotações por minuto
STL | Formato de malha empregado na fabricação aditiva
Wi-Fi | Tecnologia de comunicação em rede sem fio

iv

## Sumário

Resumo | i
Abstract | ii
Lista de figuras | iii
Lista de siglas e abreviaturas | iv
1 INTRODUÇÃO | 1
2 REFERENCIAL TEÓRICO | 3
3 METODOLOGIA E DESENVOLVIMENTO | 4
4 TESTES E VERIFICAÇÕES | 7
5 RESULTADOS E DISCUSSÃO | 8

v

6 SUSTENTABILIDADE E SEGURANÇA | 9
7 PROPOSTAS DE OTIMIZAÇÃO E EVOLUÇÃO | 9
8 CONCLUSÃO | 9
Referências | 11
Apêndice A - Repositório e materiais | 12

vi

## 1 INTRODUÇÃO

Motores elétricos convertem energia elétrica em energia mecânica por meio da interação entre campos magnéticos. No protótipo estudado, essa conversão é explorada em uma arquitetura inspirada visualmente nos motores radiais: cinco eletroímãs são distribuídos ao redor de um conjunto móvel central e acionados em sequência.
A proposta foi desenvolvida no primeiro semestre do curso de Engenharia Elétrica como exercício interdisciplinar. Além da montagem eletromecânica, o trabalho reuniu modelagem CAD, impressão 3D, programação embarcada, comunicação em rede e reaproveitamento de materiais. O resultado deve ser compreendido como protótipo experimental e didático, não como máquina elétrica caracterizada para operação contínua.

Esta versão revisada separa fatos documentados de hipóteses e observações. Afirmações

quantitativas sobre eficiência, torque, velocidade ou desempenho térmico somente poderão

ser feitas após ensaios instrumentados.

### 1.1 Problemática e justificativa

O desafio consistiu em produzir movimento rotativo a partir do acionamento coordenado de cinco bobinas, usando uma estrutura de baixo custo e um controlador programável. O aquecimento por efeito Joule motivou também a incorporação de passagens para circulação de água nos encapsulamentos das bobinas, conceito que requer validação térmica posterior. A documentação técnica é parte do problema de engenharia. Sem o registro de pinagem, lógica de controle, modelos de fabricação e limitações dos ensaios, torna-se difícil reproduzir o protótipo ou comparar futuras alterações. Assim, este relatório reúne o estado conhecido do sistema e explicita os dados que ainda precisam ser medidos.

### 1.2 Referências visuais e conceituais

A organização em estrela foi inspirada na leitura visual dos motores radiais aeronáuticos, nos quais os cilindros se distribuem ao redor de um eixo central. A semelhança é geométrica: o protótipo elétrico não reproduz combustão interna, bielas articuladas ou o ciclo termodinâmico dessas máquinas.

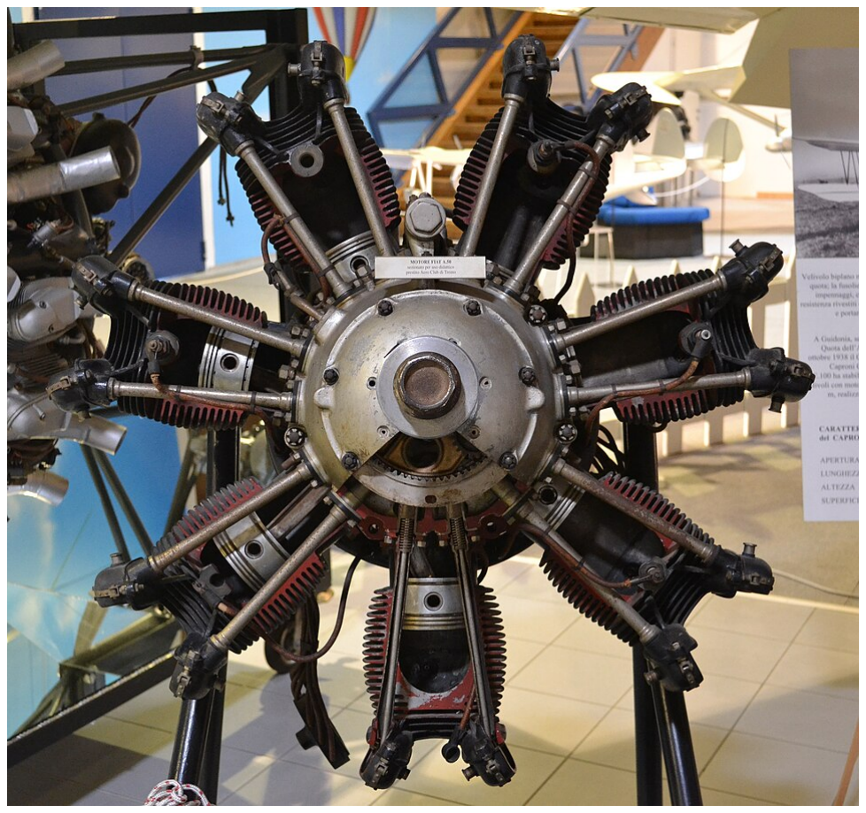
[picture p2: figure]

Figura 1: Motor aeronáutico radial Fiat A.50 seccionado, referência para a disposição em estrela.
Fonte: MLWatts, Wikimedia Commons, 2012, licença CC BY-SA 3.0.

O princípio de atuação, por sua vez, vem do campo magnético produzido por uma bobina energizada. A Figura 2 é conceitual e não representa a geometria exata dos atuadores construídos.

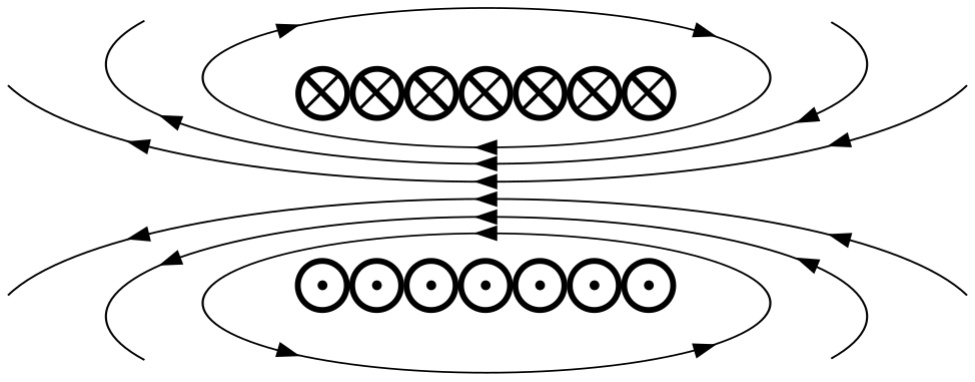
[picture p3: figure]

Figura 2: Representação aproximada das linhas de campo de um solenoide. Fonte: Nuno Nogueira, Wikimedia Commons, domínio público.

### 1.3 Objetivos

### 1.3.1 Objetivo geral

Projetar, construir e demonstrar um protótipo de motor radial elétrico com cinco atuadores, controle embarcado e componentes produzidos por fabricação aditiva.

### 1.3.2 Objetivos específicos

- modelar e fabricar suportes e encapsulamentos por impressão 3D;

- construir e testar cinco bobinas eletromagnéticas;
- implementar o acionamento sequencial por ESP32 e ULN2003;
- permitir habilitação remota por consulta a um comando hospedado no GitHub;
- investigar uma solução de circulação de água para remoção de calor;
- documentar limitações e definir ensaios para a continuidade do projeto.

## 2 REFERENCIAL TEÓRICO

### 2.1 Eletromagnetismo e atuação

A corrente elétrica que percorre uma bobina produz um campo magnético. Quando o atuador é energizado, esse campo exerce força sobre o elemento ferromagnético associado ao mecanismo móvel. A repetição ordenada das atrações produz deslocamentos angulares sucessivos. A intensidade da força depende, entre outros fatores, da corrente, do número de espiras, da geometria do núcleo e do entreferro [4, 3].

### 2.2 Aquecimento por efeito Joule

A dissipação elétrica em uma bobina pode ser estimada por

P = RI²
, | (1)

em que P é a potência dissipada, R é a resistência do enrolamento e I é a corrente. Como o aquecimento varia com o quadrado da corrente, a caracterização elétrica e térmica é essencial antes de aumentar o tempo de energização ou a tensão de alimentação.

### 2.3 Controle embarcado e estágio de potência

Os pinos do ESP32 fornecem sinais lógicos e não devem alimentar bobinas diretamente. O ULN2003 reúne transistores Darlington usados como chaves de baixa tensão, permitindo que os sinais do microcontrolador comandem cargas ligadas a uma fonte externa [8]. O

retorno de corrente, a conexão comum dos diodos internos, o aterramento compartilhado e os limites elétricos do componente precisam ser respeitados na montagem.

Comando remoto GitHub | −→ | ESP32 + Wi-Fi | −→ | ULN2003 | −→

5 bobinas

Figura 3: Arquitetura funcional documentada do protótipo. Fonte: Elaboração própria.

### 2.4 Configuração radial

Nos motores aeronáuticos radiais, cilindros são distribuídos ao redor de um eixo comum. Neste trabalho, a configuração foi reinterpretada como disposição de cinco atuadores eletromagnéticos em estrela. A comparação orienta a forma do conjunto, mas não implica equivalência entre os princípios de conversão de energia.

## 3 METODOLOGIA E DESENVOLVIMENTO

### 3.1 Fluxo de atividades

O desenvolvimento foi conduzido em etapas interdependentes:

1. definição da configuração radial e modelagem das peças;
2. impressão dos suportes e encapsulamentos;
3. construção dos enrolamentos e montagem dos elementos ferromagnéticos;
4. integração mecânica sobre a base de madeira;
5. montagem do ESP32 e do estágio ULN2003;
6. desenvolvimento e compilação do firmware;
7. teste individual das cinco saídas;
8. execução da sequência e registro da demonstração.

### 3.2 Componentes utilizados

Tabela 1: Componentes identificados na documentação disponível.

Componente | Função no protótipo
ESP32 | Sequenciamento das bobinas e consulta ao comando remoto
| por Wi-Fi.
ULN2003 | Chaveamento das cargas a partir dos sinais lógicos do ESP32.
Cinco bobinas | Produção dos campos magnéticos de atuação.
Fonte externa | Alimentação do estágio de potência e dos enrolamentos.
Peças impressas em 3D | Suporte das bobinas e encapsulamento com passagens para
| água.
Base de madeira | Sustentação do conjunto eletromecânico.
Componentes metá- licos | Elementos móveis, eixo e partes ferromagnéticas.
Tubulações e reserva- tório | Circulação experimental de água nos encapsulamentos.

### 3.3 Estrutura mecânica e fabricação aditiva

A montagem adota cinco posições radiais em torno do rotor. A base foi construída em madeira e recebeu componentes metálicos reutilizados. Foram disponibilizadas três malhas STL: suporte da bobina e metades esquerda e direita do encapsulamento. Como o formato STL não registra unidade, as dimensões devem ser confirmadas no software CAD ou fatiador antes da fabricação.

Tabela 2: Características extraídas das malhas STL.

Modelo | Triângulos Dimensões geométricas X × Y × Z
Bobina | 1.804 | 40,00 × 39,98 × 80,00
Encapsulamento esquerdo | 766 | 29,00 × 64,27 × 80,00
Encapsulamento direito | 766 | 24,00 × 64,27 × 80,00

As dimensões da Tabela 2 são limites geométricos da malha. As unidades não são codificadas no arquivo e precisam ser confirmadas antes da impressão.

### 3.4 Subsistema eletromagnético e resfriamento

Cada atuador é formado por um enrolamento de fio de cobre esmaltado e um elemento ferromagnético móvel. Os encapsulamentos foram concebidos com passagens para água. A existência desse circuito de circulação é documentada, mas sua contribuição térmica ainda não foi quantificada por comparação de temperaturas, vazões ou tempos de operação.

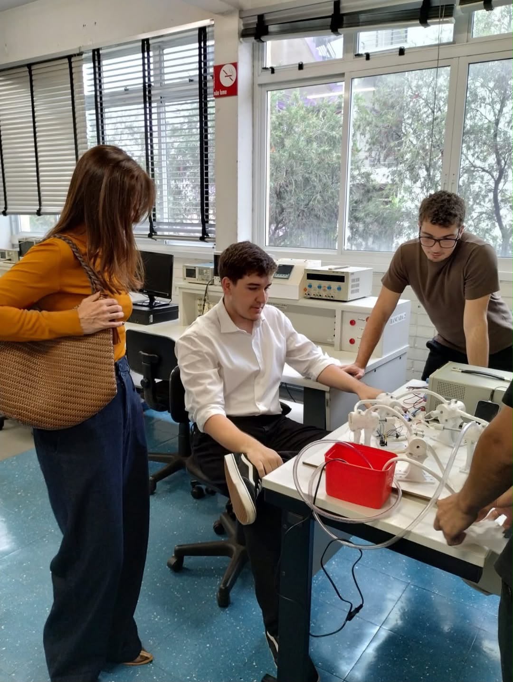
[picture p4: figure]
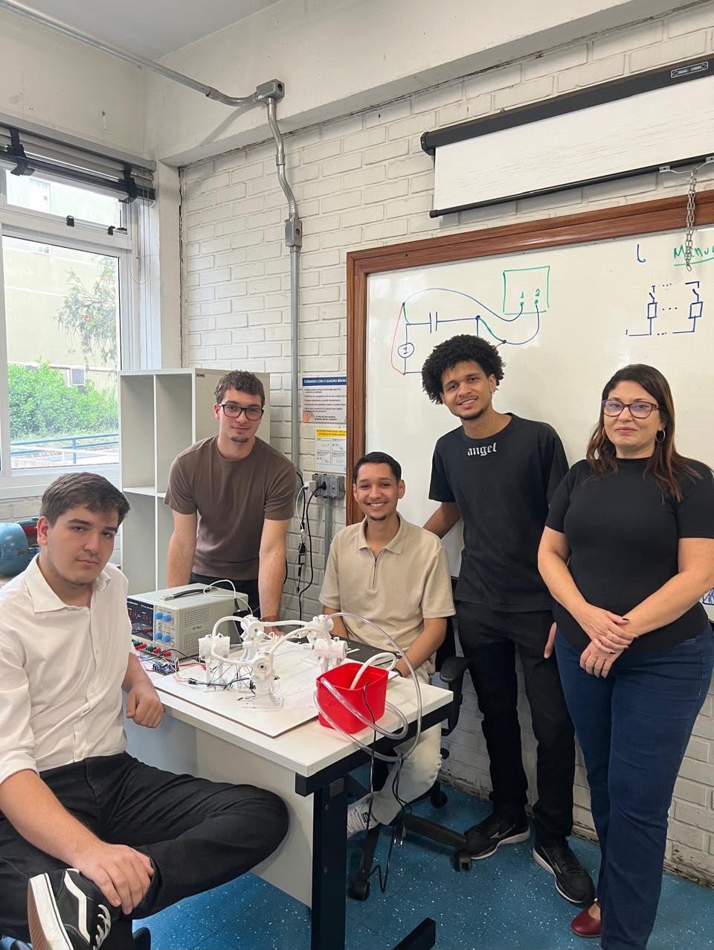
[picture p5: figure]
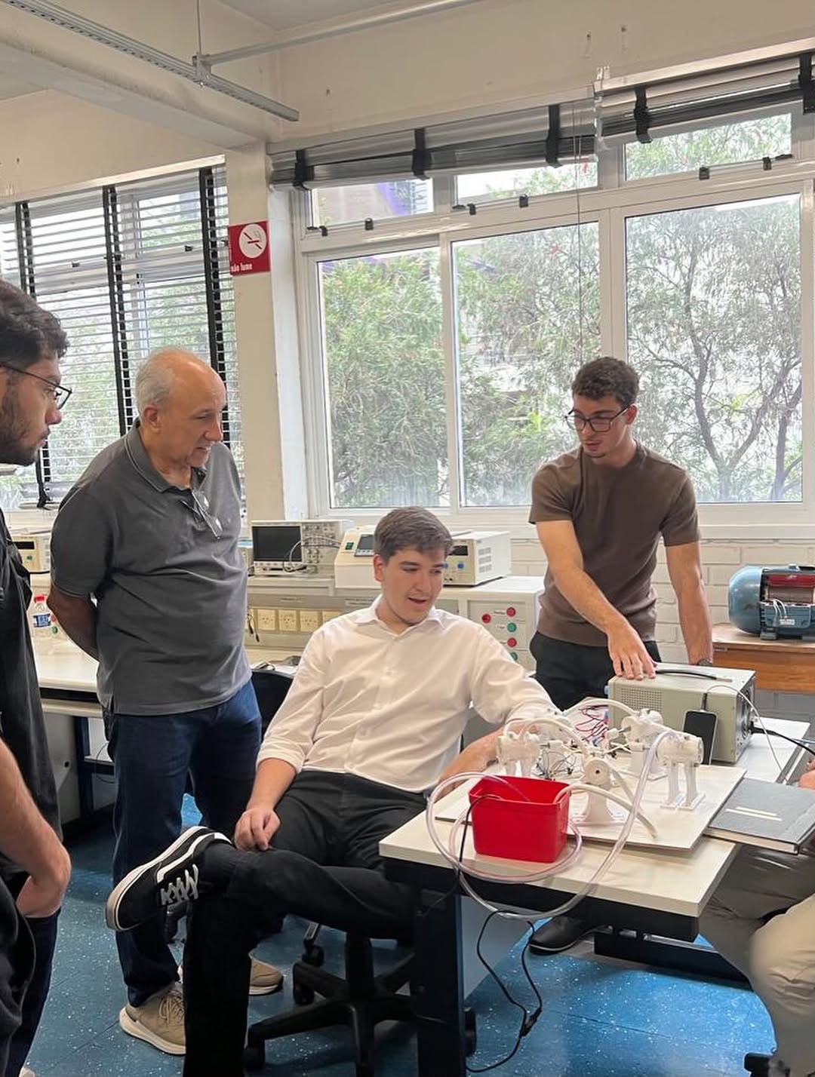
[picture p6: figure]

Figura 4: Registros do protótipo e da apresentação acadêmica. Fonte: Acervo da equipe.

### 3.5 Eletrônica e pinagem

Tabela 3: Mapeamentos definidos no firmware.

Canal lógico | GPIO no modo
| 1 | GPIO no modo
| | 2 | Função
Bobina 0 | 14 | 17 | Primeiro atuador da sequência
Bobina 1 | 17 | 25 | Segundo atuador da sequência
Bobina 2 | 27 | 14 | Terceiro atuador da sequência
Bobina 3 | 25 | 16 | Quarto atuador da sequência
Bobina 4 | 16 | 27 | Quinto atuador da sequência

O circuito completo do Tinkercad depende de autenticação para inspeção. A documenta-

ção disponível ainda não confirma tensão da fonte, resistência das bobinas, corrente por

canal, ligação do terminal COM ou capacidade térmica do driver.

### 3.6 Programação do sistema de controle

### 3.6.1 Organização geral

O firmware foi organizado em módulos para variáveis, sequenciamento e comunicação Wi-Fi. As credenciais de rede foram removidas do código versionado e substituídas por um arquivo local ignorado pelo Git. Uma tarefa FreeRTOS fixada ao segundo núcleo consulta periodicamente o comando remoto, enquanto o laço principal executa a sequência eletromagnética.

### 3.6.2 Teste de inicialização

Antes da rotina principal, as cinco saídas são acionadas individualmente. Essa etapa permite verificar a resposta de cada canal, mas deve ser executada com alimentação limitada e possibilidade de desligamento imediato.

### 3.6.3 Sequência e aceleração

A posição lógica seguinte é obtida por aritmética modular, fazendo a sequência retornar ao início após a quinta bobina. O intervalo entre passos parte de aproximadamente 800 ms e decresce exponencialmente em direção a 100 ms, com constante temporal configurada em 40 s. O número apresentado como RPM no monitor serial é uma estimativa baseada em uma relação assumida entre passos e revolução; não substitui medição por tacômetro.

Tabela 4: Modos de sequência do firmware revisado.

| Modo Ordem dos GPIOs | | Compilação
1 | 14, 17, 27, 25, 16 | Aprovada
2 | 17, 25, 14, 16, 27 | Aprovada

### 3.6.4 Comando remoto

O ESP32 realiza uma requisição HTTP ao arquivo commands.txt hospedado no GitHub. Quando recebe o texto MOTOR_ON, habilita o funcionamento; qualquer outro conteúdo desabilita o acionamento. Essa solução é adequada à demonstração, mas não oferece autenticação própria, resposta em tempo real garantida ou proteção contra indisponibilidade da rede.

## 4 TESTES E VERIFICAÇÕES

### 4.1 Verificação de software

A versão sanitizada foi compilada com Arduino CLI 1.5.1 para o alvo ESP32 Dev Module, usando o núcleo oficial Espressif esp32:esp32 3.3.11. Os dois modos de pinagem compilaram sem erro.

Tabela 5: Resultado da compilação do firmware.

Configuração | Programa | Memória global
Modo 1 | 1.022.916 bytes (78%) | 48.504 bytes (14%)
Modo 2 | 1.022.920 bytes (78%) | 48.504 bytes (14%)

Esse ensaio verifica a consistência do software e das dependências de compilação. Ele não comprova o comportamento elétrico do protótipo.

### 4.2 Testes documentados

Os materiais fornecidos incluem registros da apresentação, vídeos do motor e testes das bobinas. Esses registros permitem documentar a construção e a ocorrência de resposta eletromecânica. Não foram disponibilizados arquivos de aquisição de dados ou instrumentos de medição associados aos testes.

### 4.3 Procedimento recomendado para ensaios futuros

1. medir resistência e continuidade de cada bobina com o sistema desligado;
2. energizar um canal por vez com fonte limitada em corrente;
3. registrar tensão, corrente e temperatura em intervalos definidos;
4. verificar a ordem física das bobinas em baixa velocidade;
5. medir RPM com sensor óptico ou Hall;
6. repetir o ensaio térmico com circulação desligada e ligada;

7. registrar vazão, temperatura ambiente e tempo de operação;
8. interromper imediatamente o teste diante de aquecimento, vazamento ou travamento.

## 5 RESULTADOS E DISCUSSÃO

### 5.1 Evidências disponíveis

As fotografias e os vídeos disponibilizados registram o protótipo, a apresentação e demonstrações associadas ao motor e às bobinas. O material sustenta a conclusão qualitativa de que o conjunto foi construído e apresentado e de que houve resposta eletromecânica durante os testes. O firmware disponível também documenta o acionamento das cinco saídas e a lógica de habilitação remota.

### 5.2 Limites das conclusões

Tabela 6: Separação entre evidência disponível e caracterização pendente.

Aspecto | O que está documentado O que ainda deve ser medido
Movimento | Observação audiovisual | RPM real, estabilidade e faixa operaci-
| | onal
Atuação | Teste sequencial de cinco sa-
| ídas | Corrente, força e repetibilidade por bo-
| | bina
Térmica | Encapsulamento com circu-
| lação de água | Temperatura, vazão e comparação com
| | e sem fluxo
Desempenho | Protótipo funcional em de-
| monstração | Torque, potência mecânica, rendimento
| | e autonomia
Controle
remoto

Consulta HTTP ao GitHub Latência, falhas de rede e segurança

Sem dados instrumentais, não é possível afirmar ganho de eficiência, redução mensurável

de temperatura ou controle preciso de velocidade. Essas afirmações foram retiradas da

conclusão para preservar a validade acadêmica do relatório.

### 5.3 Relevância acadêmica

O protótipo integra conceitos de eletromagnetismo, eletrônica de potência, sistemas embarcados, programação concorrente, fabricação aditiva e segurança experimental. As limitações encontradas não anulam seu valor didático; ao contrário, definem problemas concretos de dimensionamento e instrumentação para uma próxima etapa.

## 6 SUSTENTABILIDADE E SEGURANÇA

### 6.1 Reaproveitamento de materiais

A base de madeira e os componentes metálicos reaproveitados reduziram a necessidade de aquisição de material novo. A fabricação aditiva também permitiu produzir geometrias específicas para o protótipo. Uma avaliação ambiental completa, contudo, exigiria contabilizar massa de material, consumo de impressão, descarte e possibilidade de reutilização.

### 6.2 Cuidados para novos ensaios

- usar fonte com limitação de corrente e proteção adequada;
- confirmar a corrente máxima das bobinas e a dissipação admissível do ULN2003;
- garantir aterramento comum e diodos de roda livre corretamente conectados;
- manter água e conexões hidráulicas isoladas da eletrônica;
- monitorar a temperatura dos enrolamentos e do driver;
- prever desligamento imediato e impedir contato com partes móveis;
- não operar o motor sem supervisão enquanto os limites não forem caracterizados.

## 7 PROPOSTAS DE OTIMIZAÇÃO E EVOLUÇÃO

- medir resistência e indutância de cada bobina;
- registrar tensão e corrente por canal com e sem carga;
- medir RPM por sensor óptico ou Hall e torque por bancada apropriada;
- comparar curvas de temperatura com circulação desligada e ligada;
- documentar vazão, fluido, vedação e pressão do circuito de resfriamento;
- substituir a consulta pública por uma interface autenticada e tolerante a falhas;
- validar esquemático, dimensionamento do driver e modelo exato da placa ESP32;
- preservar o arquivo CAD paramétrico e registrar parâmetros de impressão.

## 8 CONCLUSÃO

O projeto atingiu seu propósito didático ao integrar uma montagem mecânica radial, cinco atuadores eletromagnéticos, fabricação aditiva, controle por ESP32 e comunicação em rede. O protótipo e seus registros demonstram a realização prática da proposta e oferecem uma plataforma concreta para estudo de comutação, eletromagnetismo e sistemas embarcados.

A principal contribuição desta revisão é tornar explícita a diferença entre funcionamento observado e desempenho medido. A compilação do firmware foi verificada, mas as grandezas elétricas, mecânicas e térmicas permanecem sem caracterização quantitativa. A continuidade do trabalho deve priorizar esses ensaios e a segurança do estágio de potência. Com a documentação do código, das malhas STL e das limitações atuais, o projeto passa a contar com uma base mais reproduzível e tecnicamente defensável para aperfeiçoamentos futuros.

## Referências

[1] CHAPMAN, Stephen J. Fundamentos de máquinas elétricas. 5. ed. Porto Alegre: AMGH, 2013.
[2] ESPRESSIF SYSTEMS. ESP32 Series Datasheet. Documentação técnica do fa-

bricante. Disponível em: https://www.espressif.com/en/support/documents/

technical-documents. (https://www.espressif.com/en/support/documents/technical-documents) Acesso em: 27 ago. 2026.

[3] FITZGERALD, A. E.; KINGSLEY JR., C.; UMANS, S. D. Máquinas elétricas. 7. ed. Porto Alegre: Bookman, 2014.
[4] HALLIDAY, D.; RESNICK, R.; WALKER, J. Fundamentos de física. v. 3. Rio de

Janeiro: LTC, 2016.

[5] MLWATTS. Fiat A.50 radial engine front view. Wikimedia Commons, 2012. Li-

cença CC BY-SA 3.0. Disponível em: https://commons.wikimedia.org/wiki/File:

Fiat_A.50_radial_engine_front_view.JPG. (https://commons.wikimedia.org/wiki/File:Fiat_A.50_radial_engine_front_view.JPG) Acesso em: 27 ago. 2026.

[6] NOGUEIRA, Nuno. Solenoid Rotated. Wikimedia Commons, 2009. Domínio público.

Disponível em: https://commons.wikimedia.org/wiki/File:Solenoid_Rotated. svg. (https://commons.wikimedia.org/wiki/File:Solenoid_Rotated.svg) Acesso em: 27 ago. 2026.

[7] SEDRA, A. S.; SMITH, K. C. Microeletrônica. 7. ed. São Paulo: Pearson, 2015.
[8] TEXAS INSTRUMENTS. ULN200x, ULQ200x High-Voltage, High-Current Darlington Transistor Arrays. Datasheet. Disponível em: https://www.ti.com/lit/ds/

symlink/uln2003a.pdf. (https://www.ti.com/lit/ds/symlink/uln2003a.pdf) Acesso em: 27 ago. 2026.

## APÊNDICE A - REPOSITÓRIO E MATERIAIS

Repositório do projeto:
GitHub - Remote-Control-Radial-Electric-Motor (https://github.com/artartoliveira2006-boop/Remote-Control-Radial-Electric-Motor)
Sketch de origem:
Arduino Cloud - MotorRadial (https://app.arduino.cc/sketches/5fc2e5a7-c3c3-415b-b562-e2339e4dc90b?view-mode=preview)
Circuito compartilhado:
Tinkercad - circuito compartilhado (https://www.tinkercad.com/things/hriccYSg3r2-dazzling-gaaris-fulffy)
O repositório preserva o firmware sanitizado, arquivos STL, fotografias, vídeos e documentação complementar. Credenciais de rede não fazem parte dos arquivos versionados.

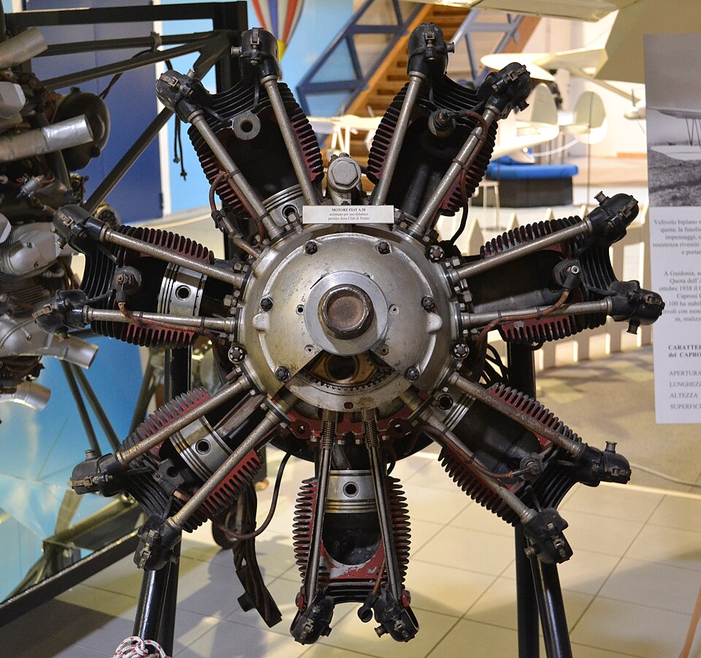
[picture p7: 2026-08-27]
media/inspiracao/motor-radial-fiat-a50.jpg

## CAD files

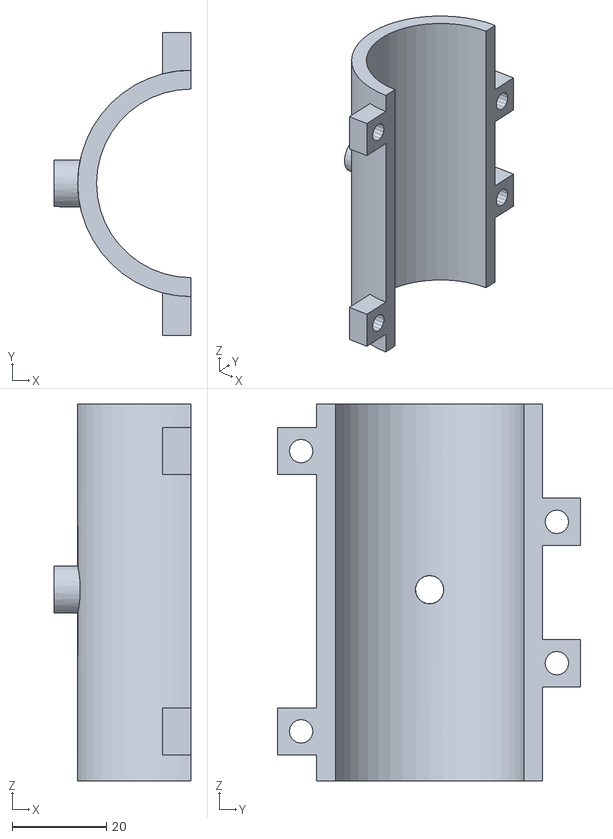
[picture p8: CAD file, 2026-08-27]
cad/encapsulamento-esquerdo.stl
29.0 x 64.3 x 80.0

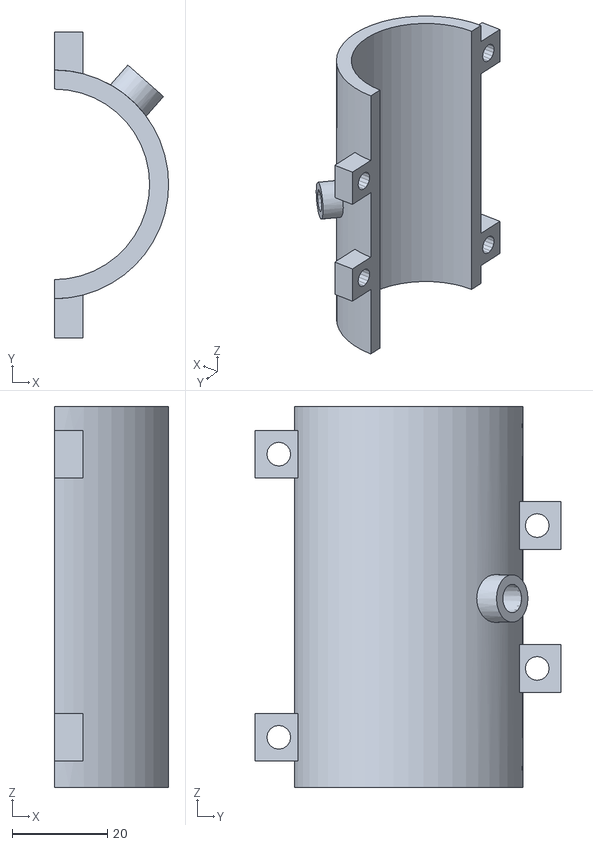
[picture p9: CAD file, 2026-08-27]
cad/encapsulamento-direito.stl
24.0 x 64.3 x 80.0

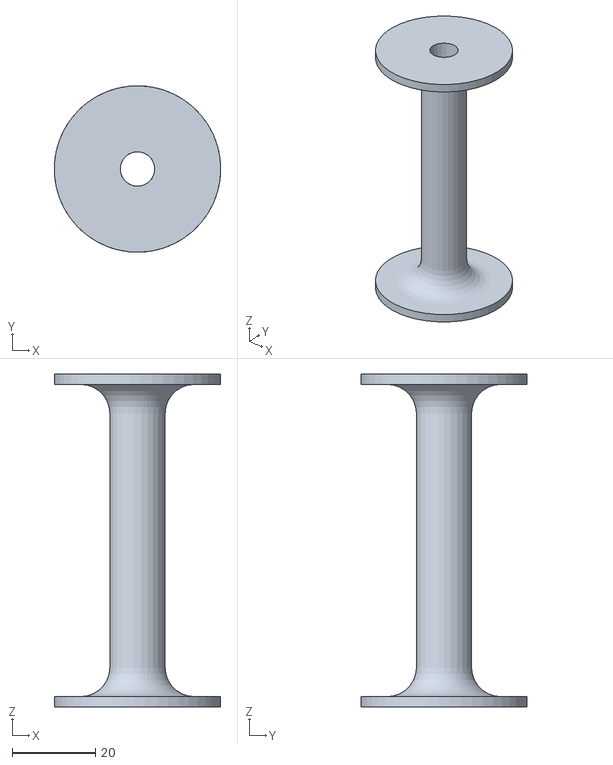
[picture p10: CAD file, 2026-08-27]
cad/bobina.stl
40.0 x 40.0 x 80.0

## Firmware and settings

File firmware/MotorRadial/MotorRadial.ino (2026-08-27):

#include "arduino_secrets.h"

#include <WiFi.h>
#include <HTTPClient.h>
#include "variaveis.h"

TaskHandle_t tarefaInternet;

void setup() {
  Serial.begin(115200);
  delay(5000);

  pinMode(COIL0_PIN, OUTPUT);
  pinMode(COIL1_PIN, OUTPUT);
  pinMode(COIL2_PIN, OUTPUT);
  pinMode(COIL3_PIN, OUTPUT);
  pinMode(COIL4_PIN, OUTPUT);
  desligarTodasAsBobinas();

  xTaskCreatePinnedToCore(
    vTarefaInternet,
    "TarefaInternet",
    10000,
    nullptr,
    1,
    &tarefaInternet,
    0
  );

  delay(500);
  conectarWifi();
  testeBobinas();
}
void vTarefaInternet(void *pvParameters) {
  (void)pvParameters;

  for (;;) {
    consultarComandoRemoto();
    vTaskDelay(10000 / portTICK_PERIOD_MS);
  }
}

void loop() {
  if (ligado && verificado) {
    sequencia();
  } else {
    desligarTodasAsBobinas();
    delay(100);
  }
}

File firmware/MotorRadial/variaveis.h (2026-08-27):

#pragma once

const char *ssid = SECRET_SSID;
const char *password = SECRET_PASSWORD;

// Arquivo publico que recebe MOTOR_ON ou MOTOR_OFF.
const char *github_raw_url =
  "https://raw.githubusercontent.com/artartoliveira2006-boop/"
  "Remote-Control-Radial-Electric-Motor/refs/heads/main/commands.txt";

// 1 = sequencial; 2 = radial/estrela.
#define MODO 1

#if MODO == 1
  const int COIL0_PIN = 14;
  const int COIL1_PIN = 17;
  const int COIL2_PIN = 27;
  const int COIL3_PIN = 25;
  const int COIL4_PIN = 16;

  const double TEMPO_INICIAL = 800.0;
  const double TEMPO_MINIMO = 100.0;
  const double TEMPO_DECAIMENTO = 40000.0;
#elif MODO == 2
  const int COIL0_PIN = 14;
  const int COIL3_PIN = 17;
  const int COIL1_PIN = 27;
  const int COIL4_PIN = 25;
  const int COIL2_PIN = 16;

  const double TEMPO_INICIAL = 500.0;
  const double TEMPO_MINIMO = 80.0;
  const double TEMPO_DECAIMENTO = 20000.0;
#else
  #error "MODO invalido. Use 1 ou 2."
#endif

volatile unsigned long tempoInicioMotor = 0;
volatile bool ligado = false;
volatile bool verificado = false;

const int n = 5;
const int k = 2;
int pProx;
int pAtual = 0;
double t;

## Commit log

2026-05-20 Add command to turn off LED
2026-05-20 Control the motor here
    use MOTOR_ON to turn the motor on
    and MOTOR_OFF to turn the motor off
    the update shall take a while to the computed by the ESP32
2026-05-20 Change MOTOR_OFF to MOTOR_ON
2026-08-27 docs: publish radial electric motor project
2026-08-27 cad: add printable motor parts
    [bobina.stl, encapsulamento-direito.stl, encapsulamento-esquerdo.stl]
